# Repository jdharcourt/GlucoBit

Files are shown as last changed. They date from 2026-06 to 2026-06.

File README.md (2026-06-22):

# GlucoBit

A CircuitPython glucose monitoring display that fetches readings from the Dexcom Share API and shows them on a colour LCD. Plays audio alarms and flashes an LED when glucose goes out of range.

**Current version:** 1.2.2

## About

GlucoBit is a standalone glucose visualisation and alert device. The product aims to solve some of the daily issues faced by Type 1 Diabetics. At present, CGMs (Continuous Glucose Monitors) send glucose data to a smartphone, where the user can access their current levels and receive alerts for low and high blood sugar events, however, missed hypoglycemic alarms, alarm fatigue, and an over-reliance on smartphones for blood glucose monitoring can cause huge issues for people with type 1 Diabetes.

One of the biggest issues faced with traditional phone-based glucose monitoring is the over-reliance on smartphones. GlucoBit solves this problem by providing a standalone, fully battery-powered device that can travel with you, displaying current glucose levels on an Always-on-display, along with glucose range indicating LEDs. The versatility of GlucoBit allows it to be used anywhere, whether that be on a bedside table, a desk at school or work, or even in an exam situation where phones for glucose monitoring and alerts are not allowed.

Also, smartphone-provided low glucose alerts are often reported to be too quiet and short to effectively alert the user, particularly when sleeping. GlucoBit addresses this problem by providing a louder, persistent alarm that continues until silenced by the user, ensuring they have been alerted to their critical glucose event.

## Hardware

| Component | Details |
|---|---|
| Display | ST7789 SPI, 280×240, rotated 90° |
| Audio | I2S speaker, plays `audio/basic.wav` for alarms |
| Touch | Capacitive sensor on A2 — wake from sleep / silence alarm |
| LED | Neopixel for glucose-level colour feedback |
| Battery | ADC for voltage and percentage |

## Features

- Fetches glucose readings every 90 seconds from the Dexcom cloud API
- Three display themes (card, split-band, minimal)
- Low / high / very-high alarms with audio and LED
- Touch-to-silence alarm
- Web UI for configuration (connect to device IP on port 80)
- Bluetooth setup and settings via the iOS companion app (see [`ios/`](ios/README.md))
- BLE reading relay: the iOS app pushes Dexcom readings to the device when its WiFi is down
- OTA updates via GitHub Releases (checked hourly)
- Deep sleep between fetches to conserve battery

## Alarm Thresholds

| Level | mmol/L | mg/dL |
|---|---|---|
| Low | < 3.9 | < 70 |
| High | > 10.0 | > 180 |
| Very High | > 13.0 | > 250 |

## Setup

1. Flash CircuitPython to your board.
2. Copy all files from this repo to the `CIRCUITPY` drive (excluding `lib/` — install Adafruit libraries separately).
3. Create `settings.json` on the device:

```json
{
  "WIFI_SSID": "your_ssid",
  "WIFI_PASSWORD": "your_password",
  "DEXCOM_USERNAME": "your_dexcom_email",
  "DEXCOM_PASSWORD": "your_dexcom_password",
  "DEXCOM_SERVER": "shareous1.dexcom.com",
  "DISPLAY_NAME": "Name",
  "BACKGROUND_COLOR": "000000",
  "MMOL": true,
  "UI_THEME": 1,
  "SETUP_MODE": false
}
```

> Use `"shareous1.dexcom.com"` for US accounts or `"share2.dexcom.com"` for international.

4. Power on — the device connects to WiFi and starts fetching readings.

## Web UI

Navigate to the device's IP address in a browser to update settings without re-flashing. Changes take effect immediately.

## File Structure

```
firmware/code.py         Entry point
firmware/app/main.py     All application logic
firmware/app/ble.py      BLE GATT server for the iOS companion app
firmware/boot.py         Remounts filesystem read-write on device
firmware/wifi.py         WiFi connection helpers
firmware/ota.py          OTA update system
firmware/audio/          Alarm sound
firmware/icons/          Trend arrow bitmaps
firmware/fonts/          Nunito BDF fonts (30pt, 40pt, 80pt)
hardware/                KiCad PCB design (ESP32-S3-WROOM-1)
ios/                     iOS companion app (SwiftUI) — see ios/README.md
```

BLE requires CircuitPython ≥ 9.0 on the device (`_bleio` on ESP32-S3). On
older builds the firmware logs "BLE unavailable" and runs WiFi-only.

## Filesystem Note

`boot.py` remounts the filesystem read-write for the device, which makes the `CIRCUITPY` drive read-only from the Mac. To write from the Mac (e.g. to edit files), hold the designated GPIO button on boot to skip the remount.

## OTA Updates

Updates are published as GitHub Releases. The device checks for a new version every hour, downloads to `/_update/`, and reboots automatically.

## License

MIT

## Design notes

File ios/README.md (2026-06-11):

# GlucoBit iOS Companion App

SwiftUI companion app for the GlucoBit glucose display. Fetches readings from
the Dexcom Share API, shows them in the device's Theme-1 style with a history
graph, configures the device over Bluetooth, and relays readings to the device
over BLE when its WiFi is down.

## Building

Requirements: Xcode 15+, [XcodeGen](https://github.com/yonaskolb/XcodeGen)
(`brew install xcodegen`).

```sh
cd ios
xcodegen generate          # creates GlucoBit.xcodeproj from project.yml
open GlucoBit.xcodeproj    # build & run from Xcode
```

The `.xcodeproj` is generated and gitignored — `project.yml` is the source of
truth. If `xcodebuild` complains that the active developer directory is
CommandLineTools, run `sudo xcode-select -s /Applications/Xcode.app/Contents/Developer`.

- **Simulator**: everything except real BLE works; the app uses a
  `MockDeviceManager` so the setup wizard and relay UI are testable.
- **Physical iPhone**: required for all real Bluetooth work. With a personal
  (free) team, provisioning profiles last 7 days. If the personal team refuses
  the App Group capability, the widget will show no data — the app itself
  falls back to its Documents directory.

## Architecture

| Component | Role |
|---|---|
| `Shared/` | Models, glucose store, theme — compiled into app **and** widget |
| `Services/DexcomShareClient` | Dexcom Share login + fetch (same API as firmware) |
| `Services/GlucoseSyncService` | Fetch → store → notifications → HealthKit → widget |
| `Bluetooth/DeviceManager` | CoreBluetooth central, state restoration, auto-reconnect |
| `Bluetooth/SettingsProvisioner` | Chunked JSON settings transfer (BEGIN/DATA/COMMIT + CRC32) |
| `Bluetooth/GlucoseRelay` | Pushes readings to the device when it reports `needs_data` |
| `GlucoBitWidget/` | Home screen + lock screen widgets reading the App Group store |

The GATT schema lives in `Bluetooth/GlucoBitGATT.swift` and must stay in sync
with `firmware/app/ble.py`.

## Background relay — what to expect

iOS background execution is restricted; the relay is designed around what is
legitimately possible:

- While the app is **connected** to the device, the device sends a status
  notification every 60 s whenever it needs data. Each notification wakes the
  app (bluetooth-central background mode) long enough to fetch from Dexcom and
  push the reading.
- If the connection drops, a **pending reconnect** stays armed and fires as
  soon as the device advertises again — including while the app is suspended.
  CoreBluetooth **state restoration** revives the app after iOS evicts it.
- **Force-quitting the app stops the relay** until it's reopened. iOS does not
  relaunch force-quit apps for Bluetooth events. The home screen shows a
  banner when relay is impossible (Bluetooth off, etc.).
- `BGAppRefreshTask` runs opportunistically (a few times a day) as a backstop
  to keep the widget and Apple Health fresh.

## Security note

Device provisioning sends WiFi and Dexcom credentials over an unencrypted BLE
connection (CircuitPython's `_bleio` has no practical pairing support). This
is a short-range, one-time transfer to your own device; don't provision in a
place where you don't trust nearby radio listeners.

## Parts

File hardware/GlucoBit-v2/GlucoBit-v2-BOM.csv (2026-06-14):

# | References | Qty | Value | Footprint | MPN | Manufacturer | Description | Unit Price | Ext. Price | Stock | Supplier P/N | Datasheet | Buy Link | DNP
1 | C1, C2 | 2 | 1uF | C_0805_2012Metric | CL05B104KP5NNNC | Samsung Electro-Mechanics | CAP CER 0.1UF 10V X7R 0402 | 0.1000 | 0.20 | 27468402 | 1276-1002-2-ND | https://mm.digikey.com/Volume0/opasdata/d220001/medias/docus/609/CL05B104KP5NNNC_Spec.pdf | https://www.digikey.com/en/products/detail/samsung-electro-mechanics/CL05B104KP5NNNC/3886660
2 | C3, C4 | 2 | 1uF | R_0603_1608Metric | CL05B104KP5NNNC | Samsung Electro-Mechanics | CAP CER 0.1UF 10V X7R 0402 | 0.1000 | 0.20 | 27468402 | 1276-1002-2-ND | https://mm.digikey.com/Volume0/opasdata/d220001/medias/docus/609/CL05B104KP5NNNC_Spec.pdf | https://www.digikey.com/en/products/detail/samsung-electro-mechanics/CL05B104KP5NNNC/3886660
3 | C5 | 1 | 10uF | C_0805_2012Metric | GRM155R60J106ME05D | Murata Electronics | CAP CER 10UF 6.3V X5R 0402 | 0.1000 | 0.10 | 766794 | 490-GRM155R60J106ME05DTR-ND | https://search.murata.co.jp/Ceramy/image/img/A01X/G101/ENG/GRM155R60J106ME05-01A.pdf | https://www.digikey.com/en/products/detail/murata-electronics/GRM155R60J106ME05D/11500166
4 | C6, C8 | 2 | 10uF | C_1206_3216Metric | GRM155R60J106ME05D | Murata Electronics | CAP CER 10UF 6.3V X5R 0402 | 0.1000 | 0.20 | 766794 | 490-GRM155R60J106ME05DTR-ND | https://search.murata.co.jp/Ceramy/image/img/A01X/G101/ENG/GRM155R60J106ME05-01A.pdf | https://www.digikey.com/en/products/detail/murata-electronics/GRM155R60J106ME05D/11500166
5 | C7 | 1 | 0.1uF | C_0603_1608Metric | CL05B104KP5NNNC | Samsung Electro-Mechanics | CAP CER 0.1UF 10V X7R 0402 | 0.1000 | 0.10 | 27468402 | 1276-1002-2-ND | https://mm.digikey.com/Volume0/opasdata/d220001/medias/docus/609/CL05B104KP5NNNC_Spec.pdf | https://www.digikey.com/en/products/detail/samsung-electro-mechanics/CL05B104KP5NNNC/3886660
6 | C9, C10 | 2 | 0.1uF | C_0805_2012Metric | CL05B104KP5NNNC | Samsung Electro-Mechanics | CAP CER 0.1UF 10V X7R 0402 | 0.1000 | 0.20 | 27468402 | 1276-1002-2-ND | https://mm.digikey.com/Volume0/opasdata/d220001/medias/docus/609/CL05B104KP5NNNC_Spec.pdf | https://www.digikey.com/en/products/detail/samsung-electro-mechanics/CL05B104KP5NNNC/3886660
7 | C11 | 1 | 100nF | C_0603_1608Metric | CL10E104KC8VPNC | Samsung Electro-Mechanics | CAP CER 100NF 100V X8L 0603 | 0.2700 | 0.27 | 445616 | 1276-CL10E104KC8VPNCTR-ND | https://mm.digikey.com/Volume0/opasdata/d220001/medias/docus/5458/CL10E104KC8VPNC_Spec.pdf | https://www.digikey.com/en/products/detail/samsung-electro-mechanics/CL10E104KC8VPNC/20498486
8 | C12, C13 | 2 | 220pF | C_0603_1608Metric | C0603C221K5RACTU | KEMET | CAP CER 220PF 50V X7R 0603 | 0.1000 | 0.20 | 933138 | 399-C0603C221K5RACTUTR-ND | https://yageogroup.com/content/datasheet/asset/file/KEM_C1002_X7R_SMD | https://www.digikey.com/en/products/detail/kemet/C0603C221K5RACTU/411073
9 | D1, D2, D3, D4 | 4 | LED | LED_0805_2012Metric | UHD111A-FKA-C3K23E1L3VG5ZB3Z3 | Cree LED | LED RGB 0404 SMD | 0.1000 | 0.40 | 147266 | 90-UHD111A-FKA-C3K23E1L3VG5ZB3Z3-ND | https://downloads.cree-led.com/files/ds/h/HB-UHD111A-FKA.pdf | https://www.digikey.com/en/products/detail/cree-led/UHD111A-FKA-C3K23E1L3VG5ZB3Z3/16833927
10 | J1 | 1 | USB-C-P16 | USB-C-P16
11 | J2, J6 | 2 | B2B-PH-K-S | JST_B2B-PH-K-S | B2B-PH-K-S | JST Sales America Inc. | CONN HEADER VERT 2POS 2MM | 0.1100 | 0.22 | 19463 | 455-1704-ND | https://www.jst-mfg.com/product/pdf/eng/ePH.pdf | https://www.digikey.com/en/products/detail/jst-sales-america-inc/B2B-PH-K-S/926611
12 | J3 | 1 | Conn_01x02_Socket | PinSocket_1x02_P2.54mm_Vertical
13 | R1 | 1 | 1M | R_0603_1608Metric | RC0402FR-071ML | YAGEO | RES 1M OHM 1% 1/16W 0402 | 0.1000 | 0.10 | 2066587 | 311-1.00MLRTR-ND | https://yageogroup.com/content/datasheet/asset/file/PYU-RC_GROUP_51_ROHS_L | https://www.digikey.com/en/products/detail/yageo/RC0402FR-071ML/726515
14 | R2 | 1 | 51k | R_0603_1608Metric | CRCW08051K00FKEA | Vishay Dale | RES SMD 1K OHM 1% 1/4W 0805 | 0.1000 | 0.10 | 1066635 | 541-1.00KCTR-ND | https://www.vishay.com/docs/20035/dcrcwe3.pdf | https://www.digikey.com/en/products/detail/vishay-dale/CRCW08051K00FKEA/1175637
15 | R3, R11, R15, R16 | 4 | 10k | R_0603_1608Metric | RC0603FR-0710KL | YAGEO | RES 10K OHM 1% 1/10W 0603 | 0.1000 | 0.40 | 12267747 | 311-10.0KHRTR-ND | https://yageogroup.com/content/datasheet/asset/file/PYU-RC_GROUP_51_ROHS_L | https://www.digikey.com/en/products/detail/yageo/RC0603FR-0710KL/726880
16 | R4 | 1 | 2k | R_0603_1608Metric | RC0402FR-072KL | YAGEO | RES 2K OHM 1% 1/16W 0402 | 0.1000 | 0.10 | 2216148 | 311-2KLRTR-ND | https://yageogroup.com/content/datasheet/asset/file/PYU-RC_GROUP_51_ROHS_L | https://www.digikey.com/en/products/detail/yageo/RC0402FR-072KL/2827565
17 | R5, R6 | 2 | 150 | R_0603_1608Metric | 150 | Keystone Electronics | BATT HOLDER C 3 CELL SOLDER LUG | 12.1000 | 24.20 | 279 | 36-150-ND | https://www.keyelco.com/userAssets/file/K75p23.pdf | https://www.digikey.com/en/products/detail/keystone-electronics/150/2745551
18 | R7 | 1 | 100 | R_0603_1608Metric | 100 | Keystone Electronics | BATT CONTACT CLIP AA SOLDER LUG | 1.2900 | 1.29 | 1001 | 36-100-ND | https://www.keyelco.com/userAssets/file/K75p22.pdf | https://www.digikey.com/en/products/detail/keystone-electronics/100/315141
19 | R8, R9 | 2 | 5.1k | R_0603_1608Metric | ERJ-2RKF5101X | Panasonic Industry | RES SMD 5.1K OHM 1% 1/10W 0402 | 0.1000 | 0.20 | 738587 | P5.10KLTR-ND | https://industrial.panasonic.com/cdbs/www-data/pdf/RDA0000/AOA0000C304.pdf | https://www.digikey.com/en/products/detail/panasonic-industry/ERJ-2RKF5101X/1746242
20 | R10, R13 | 2 | 100k | R_0603_1608Metric | RC0402FR-07100KL | YAGEO | RES 100K OHM 1% 1/16W 0402 | 0.1000 | 0.20 | 12945540 | 311-100KLRTR-ND | https://yageogroup.com/content/datasheet/asset/file/PYU-RC_GROUP_51_ROHS_L | https://www.digikey.com/en/products/detail/yageo/RC0402FR-07100KL/726526
21 | R14 | 1 | 220k | R_0603_1608Metric | CRCW040220K0FKED | Vishay Dale | RES 20K OHM 1% 1/16W 0402 | 0.1000 | 0.10 | 923985 | 541-20.0KLTR-ND | https://www.vishay.com/docs/20035/dcrcwe3.pdf | https://www.digikey.com/en/products/detail/vishay-dale/CRCW040220K0FKED/1178153
22 | SW1 | 1 | RESET | PTS810_CNK | NC7SZ175P6X | onsemi | IC FF D-TYPE SINGLE 1BIT SC-88 | 0.1000 | 0.10 | 142234 | NC7SZ175P6XTR-ND | https://www.onsemi.com/pub/Collateral/NC7SZ175-D.PDF | https://www.digikey.com/en/products/detail/onsemi/NC7SZ175P6X/673370
23 | SW2 | 1 | BOOT | PTS810_CNK | PD-CAP-1/8-0 | TE Connectivity Raychem Cable Protection | HEATSHRINK CAP BLACK | 0.1700 | 0.17 | 22435 | PDC018K-ND | https://www.te.com/commerce/DocumentDelivery/DDEController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 | https://www.digikey.com/en/products/detail/te-connectivity-raychem-cable-protection/PD-CAP-1-8-0/1825232
24 | U1 | 1 | ESP32-S3-WROOM-1-N8 | ESP32-S3-WROOM-1 | ESP32-S3-WROOM-1-N8 | Espressif Systems | RF TXRX MODULE WIFI PCB TRACE | 5.6600 | 5.66 | 3012 | 5407-ESP32-S3-WROOM-1-N8TR-ND | https://www.espressif.com/sites/default/files/documentation/esp32-s3-wroom-1_wroom-1u_datasheet_en.pdf | https://www.digikey.com/en/products/detail/espressif-systems/ESP32-S3-WROOM-1-N8/15200089
25 | U2 | 1 | BQ24040DSQR | DSQ10_P9X1P5 | BQ24040DSQR | Texas Instruments | IC BATT CHG LI-ION 1CELL 10SON | 0.9500 | 0.95 | 25428 | 296-37142-2-ND | https://www.ti.com/lit/ds/symlink/bq24040.pdf | https://www.digikey.com/en/products/detail/texas-instruments/BQ24040DSQR/2231631
26 | U3 | 1 | TLV75801PDBV | SOT-23-5 | TLV75801PDBVR | Texas Instruments | IC REG LIN POS ADJ 500MA SOT23-5 | 0.3100 | 0.31 | 60801 | 296-TLV75801PDBVRTR-ND | https://www.ti.com/general/docs/suppproductinfo.tsp?distId=10 | https://www.digikey.com/en/products/detail/texas-instruments/TLV75801PDBVR/10715374
27 | U4 | 1 | USBLC6-2SC6 | SOT95P280X145-6N | USBLC6-2SC6 | Shenzhen Slkormicro Semicon Co., Ltd. | 6A@8/20US 13V 78W@8/20US 9V 5V S | 0.1700 | 0.17 | 12024 | 5399-USBLC6-2SC6TR-ND | https://mm.digikey.com/Volume0/opasdata/d220001/medias/docus/7833/USBLC6-2SC6%20SOT-23-6L.PDF | https://www.digikey.com/en/products/detail/shenzhen-slkormicro-semicon-co-ltd/USBLC6-2SC6/28143029
28 | U5 | 1 | MAX98357AETE+T | DAC | MAX98357AETE+T | Analog Devices Inc./Maxim Integrated | IC AMP CLASS D MONO 3.2W 16TQFN | 3.7300 | 3.73 | 22470 | MAX98357AETE+TTR-ND | https://datasheets.maximintegrated.com/en/ds/MAX98357A-MAX98357B.pdf | https://www.digikey.com/en/products/detail/analog-devices-inc-maxim-integrated/MAX98357AETE-T/4936122
29 | U6 | 1 | 08JQ-BT | JSTx8 | 08JQ-BT | JST Sales America Inc. | CONN RCPT 8POS 0.098 TIN PCB | 0.5100 | 0.51 | 892 | 455-2970-ND | https://www.jst-mfg.com/product/pdf/eng/eJQ.pdf | https://www.digikey.com/en/products/detail/jst-sales-america-inc/08JQ-BT/4918702
30 | V1 | 1 | 2.2 |  | T18S9M4 | HellermannTyton | CBL TIE LOCKING NAT 18LB 3.27" | 0.0232 | 0.02 | 57900 | 1436-1516-ND | https://assets.hellermanntyton.us/m/2164f83b29279c64/original/TDS_111-02809_us.pdf | https://www.digikey.com/en/products/detail/hellermanntyton/T18S9M4/4290367
 | TOTAL | 45 |  |  |  |  |  |  | 40.40

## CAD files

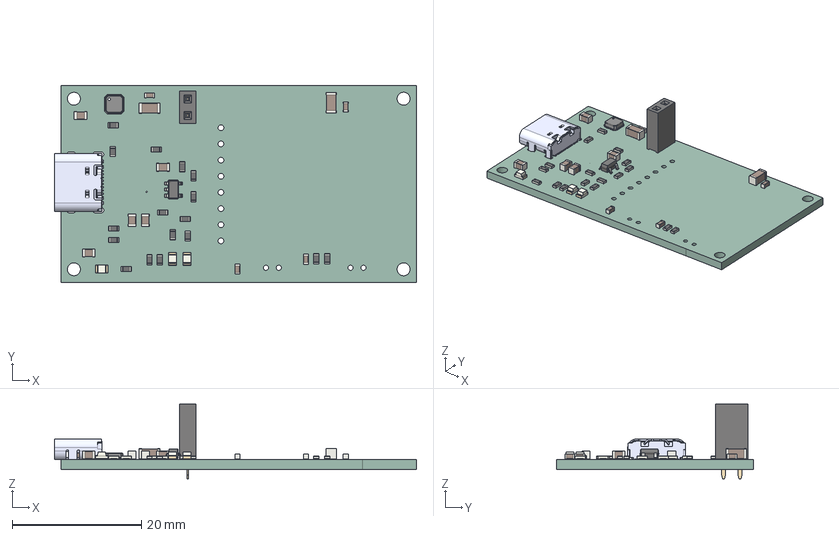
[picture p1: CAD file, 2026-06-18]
hardware/GlucoBit-v2/GlucoBit-v2.step
56.0 x 30.4 x 11.6 mm
R_0603_1608Metric x 17
LED_0805_2012Metric x 3
C_0805_2012Metric x 5
Same_Sky_UJ20-C-H-G-SMT-1-P16-TR
C_0603_1608Metric x 4
SOT-23-5
MAX98357AETE_T
C_1206_3216Metric x 2
PinSocket_1x02_P2.54mm_Vertical
GlucoBit-v2_PCB

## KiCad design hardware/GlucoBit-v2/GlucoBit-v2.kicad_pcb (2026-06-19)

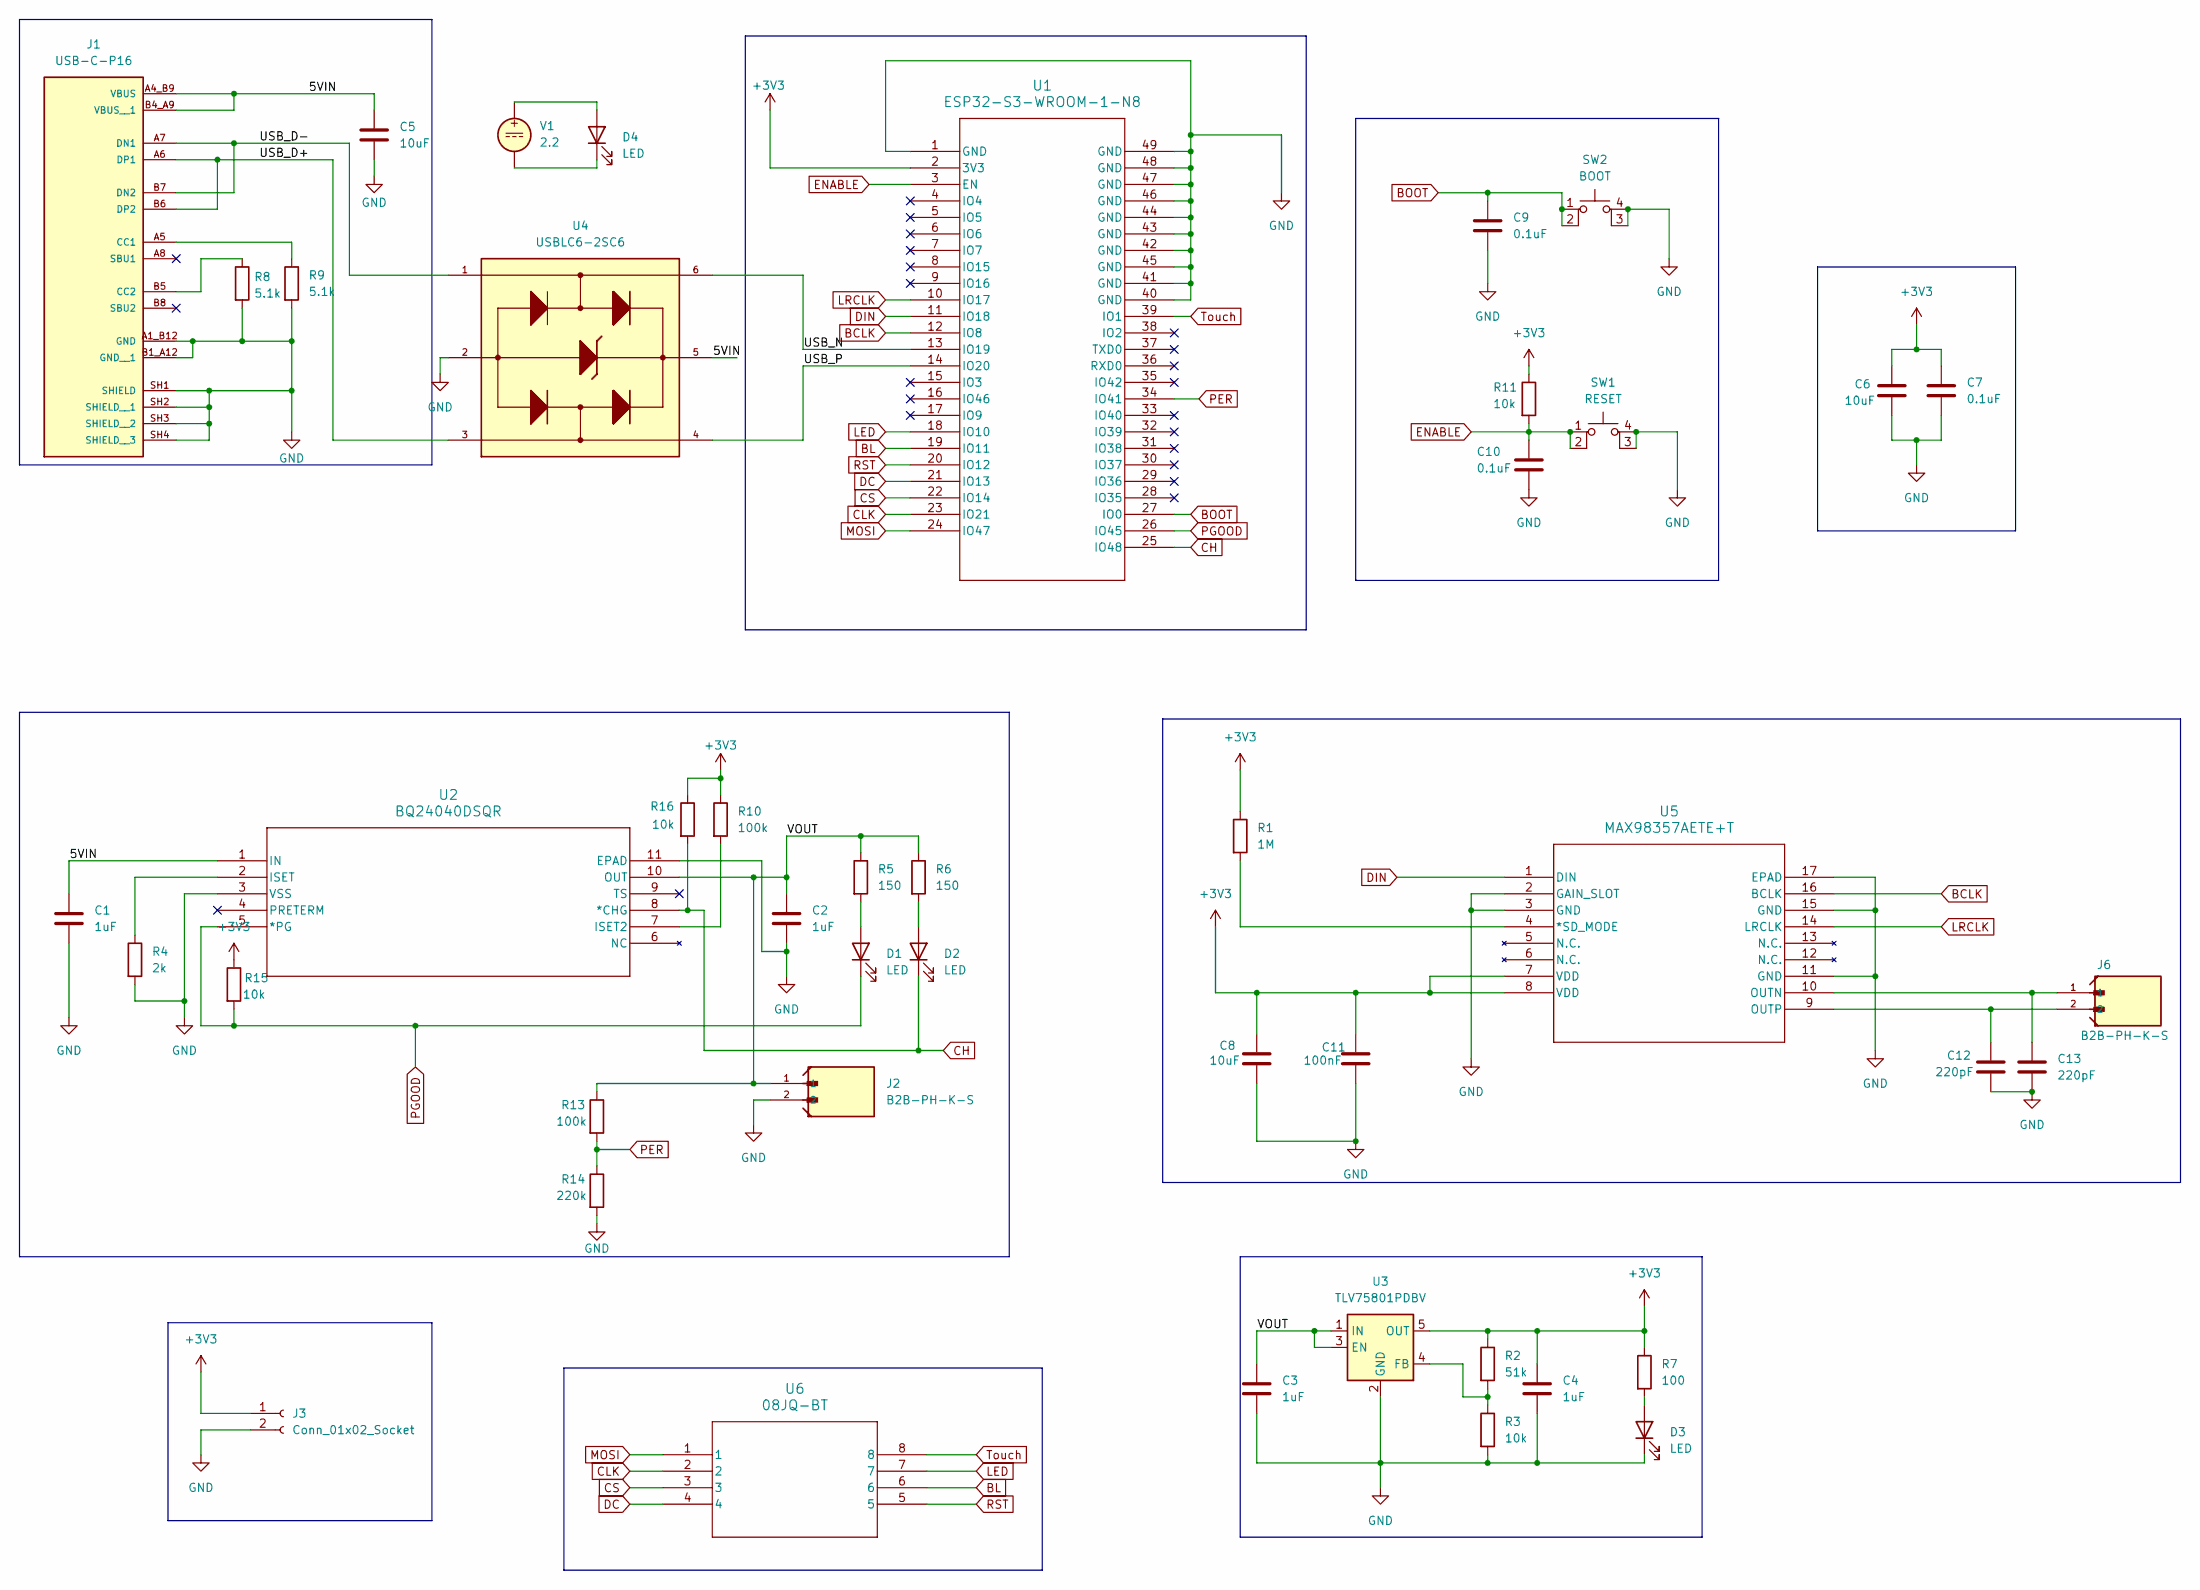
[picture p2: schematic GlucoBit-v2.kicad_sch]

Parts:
C1, C2: 1uF; C_0805_2012Metric
C3, C4: 1uF; R_0603_1608Metric
C5: 10uF; C_0805_2012Metric
C6, C8: 10uF; C_1206_3216Metric
C7: 0.1uF; C_0603_1608Metric
C9, C10: 0.1uF; C_0805_2012Metric
C11: 100nF; C_0603_1608Metric
C12, C13: 220pF; C_0603_1608Metric
D1, D2, D3, D4: LED; LED_0805_2012Metric
J1: USB-C-P16; PARTREV 1.0
J2, J6: B2B-PH-K-S; JST_B2B-PH-K-S
J3: Conn_01x02_Socket; PinSocket_1x02_P2.54mm_Vertical
R1: 1M; R_0603_1608Metric
R2: 51k; R_0603_1608Metric
R3, R11, R15, R16: 10k; R_0603_1608Metric
R4: 2k; R_0603_1608Metric
R5, R6: 150; R_0603_1608Metric
R7: 100; R_0603_1608Metric
R8, R9: 5.1k; R_0603_1608Metric
R10, R13: 100k; R_0603_1608Metric
R14: 220k; R_0603_1608Metric
SW1: RESET; PTS810_CNK
SW2: BOOT; PTS810_CNK
U1: ESP32-S3-WROOM-1-N8; ESP32-S3-WROOM-1
U2: BQ24040DSQR; DSQ10_P9X1P5
U3: TLV75801PDBV; SOT-23-5
U4: USBLC6-2SC6; SOT95P280X145-6N
U5: MAX98357AETE+T; DAC
U6: 08JQ-BT; JSTx8
V1: 2.2

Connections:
+3V3: C4.1, C6.1, C7.1, C8.1, C11.1, J3.1, R1.1, R2.1, R7.1, R10.1, R11.1, R15.1, R16.1, U1.2 (3V3), U3.5 (OUT), U5.7 (VDD), U5.8 (VDD)
/5VIN: C1.1, C5.1, J1.A4_B9 (VBUS), J1.B4_A9 (VBUS__1), U2.1 (IN), U4.5
/USB_D+: J1.A6 (DP1), J1.B6 (DP2), U4.3
/USB_D-: J1.A7 (DN1), J1.B7 (DN2), U4.1
/USB_N: U1.13 (IO19), U4.6
/USB_P: U1.14 (IO20), U4.4
/VOUT: C2.1, C3.1, J2.1, R5.1, R6.1, R13.1, U2.10 (OUT), U3.1 (IN), U3.3 (EN)
BCLK: U1.12 (IO8), U5.16 (BCLK)
BL: U1.19 (IO11), U6.6
BOOT: C9.1, SW2.1, SW2.2, U1.27 (IO0)
CH: D2.1 (K), R16.2, U1.25 (IO48), U2.8 (*CHG)
CLK: U1.23 (IO21), U6.2
CS: U1.22 (IO14), U6.3
DC: U1.21 (IO13), U6.4
DIN: U1.11 (IO18), U5.1 (DIN)
ENABLE: C10.1, R11.2, SW1.1, SW1.2, U1.3 (EN)
GND: C1.2, C2.2, C3.2, C4.2, C5.2, C6.2, C7.2, C8.2, C9.2, C10.2, C11.2, C12.2, C13.2, D3.1 (K), J1.A1_B12 (GND), J1.B1_A12 (GND__1), J1.SH1 (SHIELD), J1.SH2 (SHIELD__1), J1.SH3 (SHIELD__2), J1.SH4 (SHIELD__3), J2.2, J3.2, R3.2, R4.2, R8.2, R9.2, R14.2, SW1.3 (K), SW1.4 (A), SW2.3 (K), SW2.4 (A), U1.1 (GND), U1.40 (GND), U1.41 (GND), U1.42 (GND), U1.43 (GND), U1.44 (GND), U1.45 (GND), U1.46 (GND), U1.47 (GND), U1.48 (GND), U1.49 (GND), U2.3 (VSS), U2.11 (EPAD), U2.V, U3.2 (GND), U4.2, U5.2 (GAIN_SLOT), U5.3 (GND), U5.11 (GND), U5.15 (GND), U5.17 (EPAD)
LED: U1.18 (IO10), U6.7
LRCLK: U1.10 (IO17), U5.14 (LRCLK)
MOSI: U1.24 (IO47), U6.1
unnamed: D1.2 (A), R5.2
unnamed: D2.2 (A), R6.2
unnamed: D3.2 (A), R7.2
unnamed: D4.1 (K), V1.2
unnamed: D4.2 (A), V1.1
unnamed: J1.A5 (CC1), R9.1
unnamed: J1.B5 (CC2), R8.1
unnamed: R10.2, U2.7 (ISET2)
unnamed: R4.1, U2.2 (ISET)
unnamed: R2.2, R3.1, U3.4 (FB)
unnamed: R1.2, U5.4 (*SD_MODE)
unnamed: C13.1, J6.1, U5.10 (OUTN)
unnamed: C12.1, J6.2, U5.9 (OUTP)
PER: R13.2, R14.1, U1.34 (IO41)
PGOOD: D1.1 (K), R15.2, U1.26 (IO45), U2.5 (*PG)
RST: U1.20 (IO12), U6.5
Touch: U1.39 (IO1), U6.8

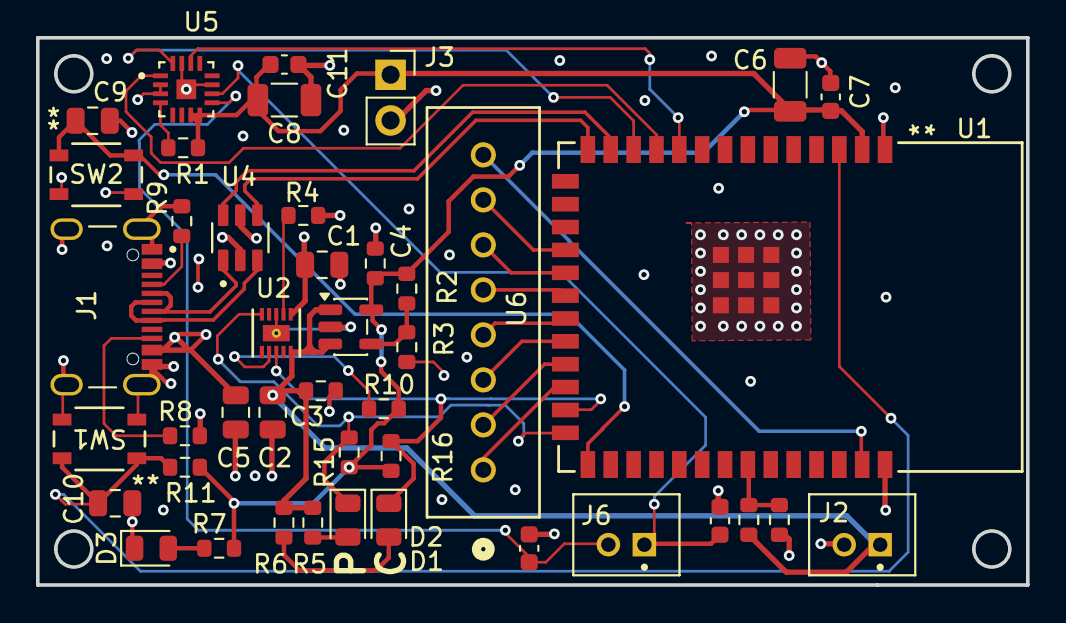
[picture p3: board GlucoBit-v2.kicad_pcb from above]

Board: 4 copper layers, 55.0 x 30.4 mm, 43 parts (0 on the bottom side), 35 nets.

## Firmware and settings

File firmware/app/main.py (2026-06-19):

import time
import audiobusio
import audiomixer
import board
import wifi
import socketpool
import ssl
import displayio
import json
import touchio
import os
import gc
import alarm
import terminalio
from adafruit_display_text import label
import adafruit_st7789
import fourwire
import adafruit_requests
import adafruit_bitmap_font.bitmap_font as bitmap_font
from adafruit_httpserver import Server, Request, Response, MIMETypes
from adafruit_display_shapes.roundrect import RoundRect
import analogio
import pwmio
import busio
import microcontroller
import adafruit_ntp
import neopixel
import array
import math
import audiocore

import adafruit_imageload
import rtc
from ota import check_and_update



    
# Check if woken from sleep
if alarm.sleep_memory[0] == 1:
    print("Woke from deep sleep (touch)")
    alarm.sleep_memory[0] = 0
    
    # Reset touch on wake
    try:
        import touchio
        # Deinit touch
        touchio.TouchIn(board.A2).deinit()
    except:
        pass
    
    gc.collect()
    time.sleep(0.5)  



MIMETypes.configure(default_to="text/plain")


alarm_active = False
alarm_suppressed = False
last_low = None
last_reading = None
last_triggered_value = None
last_glucose_cache = None  # (value, trend, latest_reading_time, prev_value)
no_data_warning_active = False
pending_developer_alarm = False
next_glucose_fetch_time = 0

LOW = 2
HIGH = 17

last_ssid = None

session = None
web_server = None
previous_glucose = None
pending_wifi_reconnect = False
pending_session_refresh = False
pending_display_refresh = False
ntp_synced = False
last_ntp_attempt = 0

main_group: displayio.Group | None = None
time_label: label.Label | None = None
ui_refs = {}
ui_signature = None

# BLE companion-app link (initialised after network setup)
ble_link = None
ble_pushed = None  # (value_mgdl, trend_str, epoch_ts, prev_value) from the app
last_reading_epoch = None  # epoch seconds of the newest displayed reading
last_reading_monotonic = None  # time.monotonic() when it was displayed

FORCE_ALARM_TEST = False
LED_TEST = False

# OTA check interval in seconds; keep this conservative to avoid network churn.
version_check = 3600
ntp_retry_interval = 60
ntp_refresh_interval = 3600
glucose_retry_interval = 20
glucose_error_retry_interval = 60
glucose_fallback_interval = 90
glucose_reading_interval = 300
glucose_reading_grace = 12



BCLK = board.D5    
LRCLK = board.D6  
DIN = board.D4    
audio = audiobusio.I2SOut(bit_clock=BCLK, word_select=LRCLK, data=DIN)


mixer = audiomixer.Mixer(
    voice_count=1,
    sample_rate=44100,
    channel_count=1,
    bits_per_sample=16,
    samples_signed=True
)
pixel_pin = board.A3
num_pixels = 2

COLOR_STOPS = [
    (3.0,  (255, 50, 0)),    # bright red-orange
    (4.0,  (255, 180, 0)),   # strong yellow
    (5.0,  (0, 180, 0)),     # vivid green
    (7.0,  (0, 100, 255)),   # deep blue
    (10.0, (120, 0, 255)),   # rich purple
    (13.0, (80, 0, 120)),    # dark indigo
    (15.0, (200, 0, 150))    # bold magenta
]




pixels = neopixel.NeoPixel(pixel_pin, num_pixels, brightness=0.3, auto_write=False)

def lerp(a, b, t):
    return a + (b-a) * t

def lerp_color(c1, c2, t):
    return (
        int(lerp(c1[0], c2[0], t)),
        int(lerp(c1[1], c2[1], t)),
        int(lerp(c1[2], c2[2], t)),
        
    )

def glucose_to_rgb(glucose):
    # Clamp 
    if glucose <= COLOR_STOPS[0][0]:
        return COLOR_STOPS[0][1]
    if glucose >= COLOR_STOPS[-1][0]:
        return COLOR_STOPS[-1][1]

    # Find the two surrounding stops
    for i in range(len(COLOR_STOPS) - 1):
        g1, c1 = COLOR_STOPS[i]
        g2, c2 = COLOR_STOPS[i + 1]

        if g1 <= glucose <= g2:
            t = (glucose - g1) / (g2 - g1)
            r = int(lerp(c1[0], c2[0], t))
            g = int(lerp(c1[1], c2[1], t))
            b = int(lerp(c1[2], c2[2], t))
            return (r, g, b)




touch_start_time = None
previous_glucose = None

touch = None              
touch_mode = "sleep"

#initialise touch sensor to detect "Sleep"
def init_sleep_touch():
    global touch, touch_mode
    cleanup_touch()                            
    for _ in range(8):
        try:
            touch = touchio.TouchIn(board.A2)
            time.sleep(0.15)
            touch.threshold = touch.raw_value + 1200
            touch_mode = "sleep"
            print("Sleep touch initialized")
            return True
        except Exception as e:
            print("Sleep touch init failed:", e)
            cleanup_touch()
            time.sleep(0.1)
    print("Failed to init sleep touch")
    return False


#Initialise Touch Sensor when alarm is playing
def init_alarm_touch():
    global touch, touch_mode
    cleanup_touch() 
    for _ in range(8):
        try:
            touch = touchio.TouchIn(board.A2)
            time.sleep(0.08)
            touch.threshold = touch.raw_value + 400
            touch_mode = "alarm"
            print("ALARM TOUCH INITIALIZED – instant response")
            return True
        except Exception as e:
            print("Alarm touch init failed:", e)
            cleanup_touch()
            time.sleep(0.08)
    print("Failed to init alarm touch")
    return False



def cleanup_touch():
    global touch
    if touch is not None:
        try:
            touch.deinit()
        except:
            pass
        touch = None
    gc.collect()



def init_hardware():
    global display, display_bus, touch, backlight

    # Re-initialise display
    displayio.release_displays()
    spi = busio.SPI(clock=board.D8, MOSI=board.D10)
    while not spi.try_lock():
        pass
    spi.configure(baudrate=24000000)
    spi.unlock()

    display_bus = fourwire.FourWire(spi, command=board.D1, chip_select=board.D0, reset=board.D7)
    display = adafruit_st7789.ST7789(
        display_bus, width=280, height=240, rotation=90, colstart=0, rowstart=20
    )
    backlight.duty_cycle = 65535
    
    splash = displayio.Group()
    init_sleep_touch()
    



    


# fonts
try:
    font_40 = bitmap_font.load_font("fonts/Nunito-Medium-40.bdf")
    font_30 = bitmap_font.load_font("fonts/Nunito-Medium-30.bdf")
    font_80 = bitmap_font.load_font("fonts/Nunito-Medium-80.bdf")
except Exception as e:
    print(f"Font load failed: {e}")
    from terminalio import FONT as font_40  # Fallback 

# config
SETTINGS_FILE = "settings.json"

# Settings are persisted to microcontroller.nvm (device-private, always
# writable from code) instead of a file on the CIRCUITPY flash. This decouples
# settings persistence from the shared filesystem: the device can save settings
# at any time without owning the filesystem, so the Mac can keep write access
# for pushing code. settings.json remains as a committed seed for first boot.
# Layout: 4-byte magic | 2-byte little-endian length | JSON payload.
NVM_MAGIC = b"GBS1"


def load_settings_nvm():
    """Return the settings dict stored in NVM, or None if absent/invalid."""
    nvm = microcontroller.nvm
    if nvm is None or len(nvm) < 6 or bytes(nvm[0:4]) != NVM_MAGIC:
        return None
    n = int.from_bytes(bytes(nvm[4:6]), "little")
    if n == 0 or n > len(nvm) - 6:
        return None
    try:
        return json.loads(bytes(nvm[6:6 + n]))
    except Exception as e:
        print("NVM settings decode failed:", e)
        return None


def save_settings_nvm(s):
    """Serialise the settings dict to NVM. Returns True on success."""
    nvm = microcontroller.nvm
    if nvm is None:
        return False
    try:
        raw = json.dumps(s).encode("utf-8")
    except Exception as e:
        print("NVM settings encode failed:", e)
        return False
    if len(raw) > len(nvm) - 6:
        print("NVM settings too large:", len(raw), "of", len(nvm) - 6)
        return False
    nvm[0:6 + len(raw)] = NVM_MAGIC + len(raw).to_bytes(2, "little") + raw
    return True

# Default settings
default_settings = {
    "WIFI_SSID": "F.B.I Surveillance Van",
    "WIFI_PASSWORD": "9conorclune!",
    "DEXCOM_USERNAME": "jdharc",
    "DEXCOM_PASSWORD": "SVCC123!",
    "DEXCOM_SERVER": "shareous1.dexcom.com",
    "DISPLAY_NAME": "DexcomFollowerName",
    "MMOL": True,
    "UI_THEME": 1,
    "BACKGROUND_COLOR": "#070B18",
    "ALERT_LOW_MGDL": 70,
    "ALERT_HIGH_MGDL": 180,
    "NO_DATA_ALARM_ENABLED": True,
    "NO_DATA_ALARM_MINUTES": 15,
    "TIMEZONE_AUTOMATIC": True,
    "TIMEZONE_OFFSET_MINUTES": 0
}


        
# URL decoding 
def url_decode(text):
    """Simple URL decoder for common percent-encoded characters."""
    result = ""
    i = 0
    while i < len(text):
        if text[i] == '%' and i + 2 < len(text):
            try:
                hex_str = text[i + 1:i + 3]
                result += chr(int(hex_str, 16))
                i += 3
            except ValueError:
                result += text[i]
                i += 1
        else:
            result += text[i]
            i += 1
    return result.replace('+', ' ')


def normalize_alert_settings(config):
    try:
        low = int(config.get("ALERT_LOW_MGDL", 70))
    except Exception:
        low = 70
    try:
        high = int(config.get("ALERT_HIGH_MGDL", 180))
    except Exception:
        high = 180
    low = max(55, min(low, 120))
    high = max(120, min(high, 300))
    if low >= high:
        low = 70
        high = 180
    config["ALERT_LOW_MGDL"] = low
    config["ALERT_HIGH_MGDL"] = high
    config["NO_DATA_ALARM_ENABLED"] = bool(config.get("NO_DATA_ALARM_ENABLED", True))
    try:
        minutes = int(config.get("NO_DATA_ALARM_MINUTES", 15))
    except Exception:
        minutes = 15
    config["NO_DATA_ALARM_MINUTES"] = max(5, min(minutes, 60))
    config["TIMEZONE_AUTOMATIC"] = bool(config.get("TIMEZONE_AUTOMATIC", True))
    try:
        offset = int(config.get("TIMEZONE_OFFSET_MINUTES", 0))
    except Exception:
        offset = 0
    config["TIMEZONE_OFFSET_MINUTES"] = max(-720, min(offset, 840))


boot_msg = label.Label(
    terminalio.FONT,
    text="Booting...",
    color=0x00FF00,
    anchor_point=(0.5, 0.5),
    anchored_position=(140, 120)
)


# Load settings: start from defaults, seed from settings.json (committed
# defaults / first-boot provisioning), then overlay NVM which is the runtime
# source of truth once the UI has saved at least once.
settings = default_settings.copy()
if SETTINGS_FILE in os.listdir():
    try:
        with open(SETTINGS_FILE, "r") as f:
            loaded_settings = json.load(f)
        # Decode URL-encoded strings in settings
        for key, value in loaded_settings.items():
            if isinstance(value, str):
                loaded_settings[key] = url_decode(value)
        settings.update(loaded_settings)
        print("Loaded settings from file (seed).")
    except Exception as e:
        print(f"Failed to load settings: {e}")
nvm_settings = load_settings_nvm()
if nvm_settings:
    settings.update(nvm_settings)
    print("Loaded settings from NVM.")
normalize_alert_settings(settings)

# Extract settings to variables
WIFI_SSID = settings["WIFI_SSID"]
WIFI_PASSWORD = settings["WIFI_PASSWORD"]
DEXCOM_USERNAME = settings["DEXCOM_USERNAME"]
DEXCOM_PASSWORD = settings["DEXCOM_PASSWORD"]
DEXCOM_SERVER = settings["DEXCOM_SERVER"]
DISPLAY_NAME = settings["DISPLAY_NAME"]
MMOL = settings["MMOL"]
BACKGROUND_COLOR = settings.get("BACKGROUND_COLOR", "#070B18")
ALERT_LOW_MGDL = settings["ALERT_LOW_MGDL"]
ALERT_HIGH_MGDL = settings["ALERT_HIGH_MGDL"]
NO_DATA_ALARM_ENABLED = settings["NO_DATA_ALARM_ENABLED"]
NO_DATA_ALARM_MINUTES = settings["NO_DATA_ALARM_MINUTES"]
TIMEZONE_AUTOMATIC = settings["TIMEZONE_AUTOMATIC"]
TIMEZONE_OFFSET_MINUTES = settings["TIMEZONE_OFFSET_MINUTES"]
try:
    UI_THEME = int(settings.get("UI_THEME", 1))
except Exception:
    UI_THEME = 1
if UI_THEME not in (1, 2, 3):
    UI_THEME = 1


def is_setup_needed():
    return (
        not DEXCOM_USERNAME
        or not settings.get("DEXCOM_PASSWORD")
        or not WIFI_SSID
        or settings.get("SETUP_MODE", False)
    )


def apply_new_settings(updates):
    """Merge decoded settings into the current config, persist to flash and
    queue deferred application via the pending flags. Shared by the web
    /save handler and the BLE settings characteristic.

    Returns (ok, wifi_changed)."""
    global settings, UI_THEME, ntp_synced, last_ntp_attempt
    global pending_wifi_reconnect, pending_session_refresh, pending_display_refresh

    old_ssid = settings.get("WIFI_SSID")
    old_password = settings.get("WIFI_PASSWORD")
    old_timezone_offset = settings.get("TIMEZONE_OFFSET_MINUTES")

    settings.update(updates)
    normalize_alert_settings(settings)

    try:
        theme_value = int(settings.get("UI_THEME", 1))
    except Exception:
        theme_value = 1
    if theme_value not in (1, 2, 3):
        theme_value = 1
    settings["UI_THEME"] = theme_value

    if not save_settings_nvm(settings):
        print("Settings write to NVM failed.")
        return False, False
    print("Settings written to NVM.")

    globals().update(settings)

    wifi_changed = (settings.get("WIFI_SSID") != old_ssid or
                    settings.get("WIFI_PASSWORD") != old_password)
    pending_wifi_reconnect = wifi_changed
    if settings.get("TIMEZONE_OFFSET_MINUTES") != old_timezone_offset:
        ntp_synced = False
        last_ntp_attempt = 0
    pending_session_refresh = True
    pending_display_refresh = True
    return True, wifi_changed


tft_cs = board.D0
tft_dc = board.D1
tft_rst = board.D7
backlight = pwmio.PWMOut(board.D9, frequency=1000, duty_cycle=0)

if alarm.wake_alarm:
    backlight.duty_cycle = 65535
    print("awake")



init_hardware()
red_overlay = displayio.Bitmap(display.width, display.height, 1)
red_palette = displayio.Palette(1)
red_palette[0] = 0xFF0000
red_tilegrid = displayio.TileGrid(red_overlay, pixel_shader=red_palette)





    
# Trend arrows file location 
TREND_ARROWS = {
    'DoubleUp': "/icons/up.bmp", 'FortyFiveUp': "/icons/up-right.bmp", 'SingleUp': "/icons/up.bmp", 'Flat': "/icons/level.bmp", 
    "FortyFiveDown": "/icons/down-right.bmp", 'SingleDown': "/icons/down.bmp", 'DoubleDown': "/icons/down.bmp"
}

def load_rgb565(path, width, height):
    with open(path, "rb") as f:
        bitmap = displayio.Bitmap(width, height, 65536)
        for y in range(height):
            for x in range(width):
                b0 = f.read(1)
                b1 = f.read(1)
                if not b0 or not b1:
                    break
                color = (b1[0] << 8) | b0[0]
                bitmap[x, y] = color
    return bitmap

def connect_to_wifi():
    splash = displayio.Group()
    value_label = label.Label(
        terminalio.FONT, text="Connecting", color=0x00FF00, anchor_point=(0.5, 0.5), anchored_position=(140, 120)
    )
    splash.append(value_label)
    display.root_group = splash
    

    for _ in range(3):
        try:
            print("Connecting to WiFi...")
            wifi.radio.connect(WIFI_SSID, WIFI_PASSWORD)
            print("Connected:", wifi.radio.ipv4_address)
            value_label.text = f"IP: {wifi.radio.ipv4_address}"
            time.sleep(2)
            return True
        except Exception as e:
            print(f"WiFi connection failed: {e}")
            value_label.text = "WiFi Failed"
            time.sleep(2)
    return False


def sync_ntp(force=False):
    global ntp_synced, last_ntp_attempt

    if not wifi.radio.connected:
        return False

    now = time.monotonic()
    interval = ntp_refresh_interval if ntp_synced else ntp_retry_interval
    if not force and now - last_ntp_attempt < interval:
        return ntp_synced

    last_ntp_attempt = now
    try:
        ntp = adafruit_ntp.NTP(pool, server="pool.ntp.org", tz_offset=0)
        rtc.RTC().datetime = time.localtime(time.mktime(ntp.datetime) + (TIMEZONE_OFFSET_MINUTES * 60))
        ntp_synced = True
        print("RTC synced to NTP")
        print(time.localtime())
        return True
    except Exception as e:
        print("NTP sync failed:", e)
        return False


def sync_clock_from_epoch(epoch, source):
    global ntp_synced

    if ntp_synced or epoch is None or epoch < 1700000000:
        return False
    try:
        rtc.RTC().datetime = time.localtime(epoch + (TIMEZONE_OFFSET_MINUTES * 60))
        ntp_synced = True
        print(f"RTC synced from {source}")
        print(time.localtime())
        return True
    except Exception as e:
        print(f"RTC sync from {source} failed:", e)
        return False


def get_version():
    try:
        with open("/app/version.txt") as f:
            return f.read().strip()
    except:
        return "0.0.0"


def wt_to_epoch(wt):
    try:
        start = wt.index("(") + 1
        digits = ""
        for ch in wt[start:]:
            if ch.isdigit():
                digits += ch
            else:
                break
        return int(digits) // 1000
    except Exception:
        return None


def next_glucose_poll_time(reading_epoch):
    if reading_epoch is None:
        return time.monotonic() + glucose_fallback_interval
    try:
        delay = reading_epoch + glucose_reading_interval + glucose_reading_grace - time.time()
    except Exception:
        delay = glucose_fallback_interval
    if delay < glucose_retry_interval:
        delay = glucose_retry_interval
    if delay > glucose_reading_interval:
        delay = glucose_reading_interval
    return time.monotonic() + delay


def start_ap_mode():
    try:
        ap_ssid = "DexcomConfig"
        ap_password = "config123"

        # start AP
        wifi.radio.enabled = True
        wifi.radio.start_ap(ssid=ap_ssid, password=ap_password)

        ip = wifi.radio.ipv4_address_ap
        print("Access point created with SSID: {}, password: {}".format(ap_ssid, ap_password))
        print(f"My IP address is {ip}")

        splash = displayio.Group()
        splash.append(
            label.Label(
                terminalio.FONT,
                text=f"Setup Required\n\nUse the GlucoBit app\n(via Bluetooth)\n\nOr connect to WiFi:\n   {ap_ssid}\n   Pass: {ap_password}\nthen open http://{ip}/",
                color=0xFFFF00,
                anchor_point=(0.5, 0.5),
                anchored_position=(140, 120),
            )
        )
        display.root_group = splash
        return True
    except Exception as e:
        print(f"Failed to start AP mode: {e}")
        splash = displayio.Group()
        splash.append(
            label.Label(
                terminalio.FONT,
                text="AP Mode Failed",
                color=0xFF0000,
                anchor_point=(0.5, 0.5),
                anchored_position=(140, 120),
            )
        )
        display.root_group = splash
        return False
    
def screen_off():
    backlight.duty_cycle = 0
    display.root_group = None     
    
    
def get_battery_voltage(pin):
    raw = pin.value
    voltage = (raw / 65535) * 3.3 * 2  # 16-bit ADC, 3.3 V ref, divider ×2
    return voltage

def voltage_to_percent(vbat_pin):
    total = 0
    for _ in range(10):
        raw = vbat_pin.value
        voltage = (raw / 65535) * 3.3 * 2
        perc = 0
        if voltage >= 4.2:
            perc = 100
        elif voltage <= 3.0:
            perc = 0
        else:
            perc = int((voltage - 3.0) / (4.2 - 3.0) * 100)
        total += perc
        time.sleep(0.05)  
    return round(total / 10)
    

def flash_red(times: int = 8, on_time: float = 0.12, off_time: float = 0.12):
    if display.root_group is None:
        return

    group = display.root_group

    for _ in range(times):
        if not alarm_active:          # cancel if sensor is touched
            break
        group.append(red_tilegrid)
        time.sleep(on_time)
        group.remove(red_tilegrid)
        time.sleep(off_time)


def play_alarm(current_glucose):
    global alarm_active, last_triggered_value
    if alarm_active:
        return
    print("=== GLUCOSE ALARM ===")
    alarm_active = True
    # Tell the companion app the alarm is sounding (the blocking loop below
    # prevents the main loop's throttled status notify from running).
    if ble_link:
        try:
            ble_link.notify_status(force=True)
        except Exception:
            pass
    init_alarm_touch()


    audio.play(mixer)
    mixer.voice[0].level = 0.5  # 50% volume

    try:
        with open("/audio/basic.wav", "rb") as f:
            wav = audiocore.WaveFile(f)
            mixer.voice[0].play(wav)
            flash_count = 0

            while alarm_active:
                if touch and touch.value:
                    print("ALARM SILENCED BY TOUCH")
                    alarm_active = False
                    break

                # Loop audio when it finishes
                if not mixer.voice[0].playing:
                    mixer.voice[0].play(wav)

                # Flash red
                if display.root_group:
                    display.root_group.append(red_tilegrid)
                time.sleep(0.15)
                if display.root_group:
                    display.root_group.remove(red_tilegrid)
                time.sleep(0.15)
                flash_count += 1

    except Exception as e:
        print("Alarm playback error:", e)
    finally:  # Stop Alarm + Flashing
        audio.stop()
        if display.root_group and red_tilegrid in display.root_group:
            display.root_group.remove(red_tilegrid)
        cleanup_touch()
        init_sleep_touch()
        alarm_active = False


def no_data_age_seconds():
    if is_setup_needed():
        return None
    if last_reading_monotonic is None:
        return int(time.monotonic())
    return int(time.monotonic() - last_reading_monotonic)


def no_data_limit_seconds():
    return int(NO_DATA_ALARM_MINUTES) * 60
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

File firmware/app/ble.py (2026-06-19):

# GlucoBit BLE GATT server — companion-app link.
#
# Uses raw _bleio (no adafruit_ble) to keep RAM cost minimal on the
# ESP32-S3-N8 (no PSRAM). Provides:
#   - Settings Transfer (write): chunked JSON provisioning from the app
#   - Glucose Push (write): app relays Dexcom readings when WiFi is down
#   - Control/ACK (notify): acknowledgements back to the app
#   - Device Status (read/notify): wifi/setup/needs-data/alarm flags,
#     battery, reading age, firmware version
#
# GATT schema must stay in sync with ios/GlucoBit/Bluetooth/GlucoBitGATT.swift.

import struct
import time
import json

try:
    import _bleio
except ImportError:
    _bleio = None

_BASE = "C0DE00{:02X}-1B34-4C8A-9F2E-6A4D5B7C8E01"

SERVICE_UUID_BYTES = None  # set on init

# Trend codes <-> Dexcom trend strings used elsewhere in the firmware
TREND_BY_CODE = {
    0: None,
    1: "DoubleUp",
    2: "SingleUp",
    3: "FortyFiveUp",
    4: "Flat",
    5: "FortyFiveDown",
    6: "SingleDown",
    7: "DoubleDown",
    8: "NonComputable",
    9: "RateOutOfRange",
}

# Settings transfer opcodes
_OP_BEGIN = 0x01
_OP_DATA = 0x02
_OP_COMMIT = 0x03

# Control/ACK opcodes
_ACK_SETTINGS = 0x10
_ACK_GLUCOSE = 0x20
_SCAN_REQUEST = 0x30
_SCAN_BEGIN = 0x31
_SCAN_DATA = 0x32
_SCAN_COMMIT = 0x33
_SCAN_ERROR = 0x34

# ACK codes
ACK_OK = 0
ACK_CRC = 1
ACK_JSON = 2
ACK_FLASH = 3
ACK_LENGTH = 4


def _crc32(data):
    try:
        from binascii import crc32
        return crc32(data) & 0xFFFFFFFF
    except ImportError:
        # Pure-python fallback (payloads are <1 KB, so speed is fine)
        crc = 0xFFFFFFFF
        for byte in data:
            crc ^= byte
            for _ in range(8):
                crc = (crc >> 1) ^ (0xEDB88320 if crc & 1 else 0)
        return crc ^ 0xFFFFFFFF


class GlucoBitBLE:
    """Polled BLE peripheral. Call poll() from the main loop; incoming writes
    queue inside _bleio PacketBuffers, so nothing is lost while the loop is
    busy (including during the blocking alarm loop)."""

    def __init__(self, on_settings, on_glucose, get_status, on_wifi_scan=None, on_developer_command=None):
        """
        on_settings(dict) -> bool   apply merged settings; True on success
        on_glucose(value_mgdl, trend_str, ts, prev_value, prev_ts) -> bool
        get_status() -> (flags, battery, reading_age_s, (maj, min, patch))
        """
        if _bleio is None:
            raise RuntimeError("BLE not supported on this CircuitPython build")

        self._on_settings = on_settings
        self._on_glucose = on_glucose
        self._get_status = get_status
        self._on_wifi_scan = on_wifi_scan
        self._on_developer_command = on_developer_command

        self._rx_buf = bytearray(244)
        self._settings_buf = None
        self._settings_len = 0
        self._settings_crc = 0
        self._settings_written = 0
        self._last_status = None
        self._last_status_notify = 0

        adapter = _bleio.adapter
        adapter.enabled = True

        service_uuid = _bleio.UUID(_BASE.format(0x01))
        self._service = _bleio.Service(service_uuid)

        self._settings_char = _bleio.Characteristic.add_to_service(
            self._service,
            _bleio.UUID(_BASE.format(0x02)),
            properties=_bleio.Characteristic.WRITE,
            read_perm=_bleio.Attribute.NO_ACCESS,
            write_perm=_bleio.Attribute.OPEN,
            max_length=244,
            fixed_length=False,
        )
        self._control_char = _bleio.Characteristic.add_to_service(
            self._service,
            _bleio.UUID(_BASE.format(0x03)),
            properties=_bleio.Characteristic.READ | _bleio.Characteristic.NOTIFY,
            read_perm=_bleio.Attribute.OPEN,
            write_perm=_bleio.Attribute.NO_ACCESS,
            max_length=4,
            fixed_length=True,
        )
        self._glucose_char = _bleio.Characteristic.add_to_service(
            self._service,
            _bleio.UUID(_BASE.format(0x04)),
            properties=_bleio.Characteristic.WRITE,
            read_perm=_bleio.Attribute.NO_ACCESS,
            write_perm=_bleio.Attribute.OPEN,
            max_length=20,
            fixed_length=False,
        )
        self._status_char = _bleio.Characteristic.add_to_service(
            self._service,
            _bleio.UUID(_BASE.format(0x05)),
            properties=_bleio.Characteristic.READ | _bleio.Characteristic.NOTIFY,
            read_perm=_bleio.Attribute.OPEN,
            write_perm=_bleio.Attribute.NO_ACCESS,
            max_length=7,
            fixed_length=True,
        )
        self._wifi_scan_char = _bleio.Characteristic.add_to_service(
            self._service,
            _bleio.UUID(_BASE.format(0x06)),
            properties=_bleio.Characteristic.WRITE | _bleio.Characteristic.READ | _bleio.Characteristic.NOTIFY,
            read_perm=_bleio.Attribute.OPEN,
            write_perm=_bleio.Attribute.OPEN,
            max_length=244,
            fixed_length=False,
        )
        self._developer_char = _bleio.Characteristic.add_to_service(
            self._service,
            _bleio.UUID(_BASE.format(0x07)),
            properties=_bleio.Characteristic.WRITE | _bleio.Characteristic.READ | _bleio.Characteristic.NOTIFY,
            read_perm=_bleio.Attribute.OPEN,
            write_perm=_bleio.Attribute.OPEN,
            max_length=244,
            fixed_length=False,
        )

        self._settings_packets = _bleio.PacketBuffer(
            self._settings_char, buffer_size=8, max_packet_size=244
        )
        self._glucose_packets = _bleio.PacketBuffer(
            self._glucose_char, buffer_size=4, max_packet_size=20
        )
        self._wifi_scan_packets = _bleio.PacketBuffer(
            self._wifi_scan_char, buffer_size=1, max_packet_size=20
        )
        self._developer_packets = _bleio.PacketBuffer(
            self._developer_char, buffer_size=2, max_packet_size=80
        )

        self._adv_data = self._build_advertisement(service_uuid)
        self._scan_resp = self._build_scan_response()
        self._advertise()

    # ── Advertising ───────────────────────────────────────────────

    def _build_advertisement(self, service_uuid):
        # Flags: LE General Discoverable, BR/EDR not supported
        adv = bytes([0x02, 0x01, 0x06])
        # Complete list of 128-bit service UUIDs (iOS background scans
        # match on this)
        uuid128 = bytes(service_uuid.uuid128)
        adv += bytes([0x11, 0x07]) + uuid128
        return adv

    def _build_scan_response(self):
        name = b"GlucoBit"
        return bytes([len(name) + 1, 0x09]) + name
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

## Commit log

2026-06-08 Sync device code to GitHub
2026-06-10 Add PCB files to hardware dir
    [GlucoBit-v2.kicad_pcb, GlucoBit-v2.kicad_sch]
2026-06-12 Finished Routing PCB, ready for DFM
2026-06-13 Update PCB after DFM
    [GlucoBit-v2.kicad_pcb, GlucoBit-v2.kicad_sch]
2026-06-13 Syncyed KiCad Files, Created initail Gerbers for DFM
    [GlucoBit-v2-B_Cu.gbl, GlucoBit-v2-B_Mask.gbs, GlucoBit-v2-B_Paste.gbp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]
2026-06-13 Ran initial DFM, Updated routing + gerbers
    [GlucoBit-v2-B_Cu.gbl, GlucoBit-v2-B_Mask.gbs, GlucoBit-v2-B_Paste.gbp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]
2026-06-13 Ran #2 DFM, Updated routing + gerbers
    [GlucoBit-v2-B_Cu.gbl, GlucoBit-v2-B_Mask.gbs, GlucoBit-v2-B_Paste.gbp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]
2026-06-14 Update UI
    [GlucoBit-v2-BOM.csv, GlucoBit-v2-BOM.xlsx, GlucoBit-v2.csv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]
2026-06-14 Feat - Edit Device settings in app
2026-06-14 Replaced traditional data retrival polling with new method to remove stale data
    [ble.py, main.py]
2026-06-18 Generated STEP files
    [GlucoBit-v2-B_Cu.gbl, GlucoBit-v2-B_Mask.gbs, GlucoBit-v2-B_Paste.gbp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]
2026-06-18 add usb-c model
    [GlucoBit-v2.kicad_pcb]
2026-06-18 add usb-c model to pcb step
    [GlucoBit-v2.step]
2026-06-19 Add BLE WiFi scanning and smoother display updates
    [GlucoBit-v2.kicad_pcb]
2026-06-19 Edged edge case for stale data on line graph. Feat + added vibrate on hover
2026-06-19 Feat+Bug Added Developer mode to ios app and firmware Fixed Alarm sliders
    [ble.py, main.py]
